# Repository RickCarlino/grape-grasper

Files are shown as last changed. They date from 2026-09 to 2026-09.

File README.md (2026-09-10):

# Precision Grasper

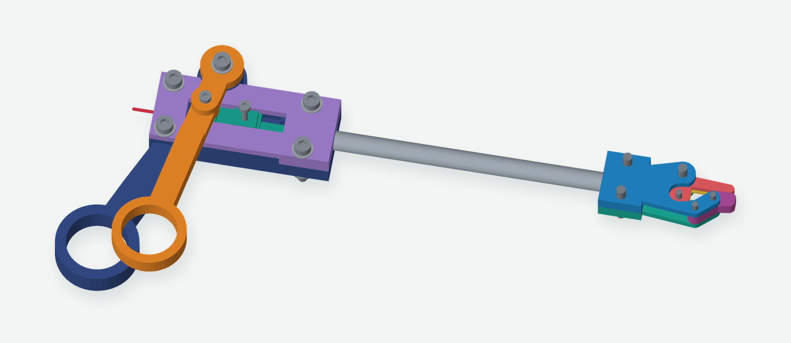
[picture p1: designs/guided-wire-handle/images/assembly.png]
Full assembly with the guided-wire lever handle and v2 printed head


A hand-operated precision grasper for dexterity practice and peeling grapes. Squeeze the lever to pull a wire through the metal tube and close the jaw; open it to push the wire back.

The newest handle provides **6 mm of wire travel** and **about 4.3:1 leverage**, matching the movement measured on the assembled v2 head. A sliding carriage guides the wire directly into the metal tube, and a through-hole lets excess wire exit the back. It reuses the v2 head, 116 mm tube, music wire, and the existing screw assortment.

**Status:** the v2 head is printed and assembled. Printing the 6 mm handle exposed a reversed cover: its print export was mirrored by mistake. **Corrected September 9:** print only the [replacement purple cover](designs/guided-wire-handle/bambu/guided-wire-cover-corrected-A1-PLA.3mf) if you already have the handle. The corrected part is digitally checked and sliced; its physical fit remains to be tested.

[Newest CAD](designs/guided-wire-handle/guided-wire-grasper.js) · [Guided-wire handle guide](designs/guided-wire-handle/README.md) · [Build log](#build-log)

## What to print

| Print | Files | Bambu A1 estimate |
| --- | --- | --- |
| Replacement purple cover — **September 9 correction** | [Cover-only 3MF](designs/guided-wire-handle/bambu/guided-wire-cover-corrected-A1-PLA.3mf) · [STL](designs/guided-wire-handle/stl/cover.stl) | **30 min / 4.83 g PLA** |
| Four guided-wire handle parts — **6 mm revision, corrected cover** | [3MF project](designs/guided-wire-handle/bambu/guided-wire-handle-A1-PLA.3mf) · [STL layout](designs/guided-wire-handle/stl/layout.stl) · [Assembly guide](designs/guided-wire-handle/README.md) | **2 hr 15 min / 28.55 g PLA** |
| Five head parts, only if you need a head | [3MF project](prints/fox-build-a1-head-v02/grape-grasper-head-v02-A1-PLA.3mf) · [Guide](docs/HEAD-V02.md) | **34 min / 4.49 g PLA** |

All projects use an A1 with a 0.4 mm nozzle, PLA, a textured PEI plate, 0.16 mm layers, and supports off. The handle uses five walls, 60% gyroid, and 2 mm brims. Confirm the installed nozzle and keep the supplied print orientations.

## The guided-wire handle

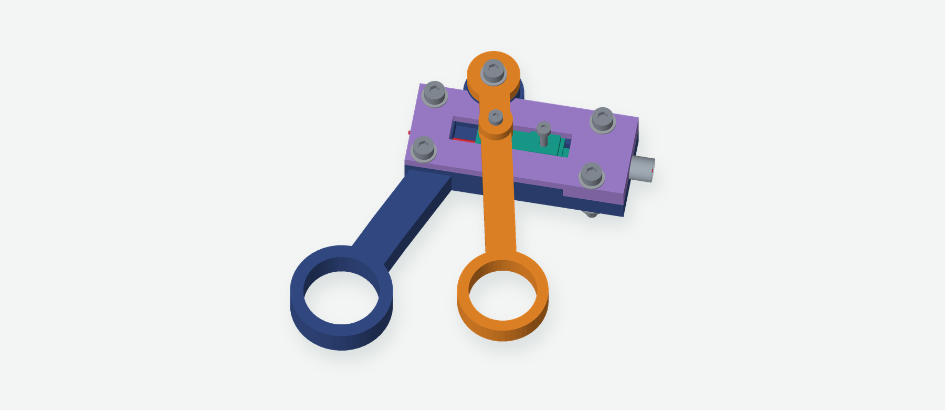
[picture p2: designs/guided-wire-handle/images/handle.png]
Guided-wire handle with its carriage cover fitted


The orange lever drives the green carriage through a metal screw engaging a transverse slot. A second screw clamps the wire directly inside the carriage. Its narrow guide telescopes into the tube, retaining at least 0.6 mm overlap during the working stroke. The wire runs beneath the drive screw and straight out of the rear frame hole, so its length is easy to adjust.

Working wire travel is **6.0 mm**, with 6.4 mm between the stops. The finger ring moves about 26 mm. The drive slot has 0.3 mm nominal reversal play. The stops limit travel, not gripping force. The full-assembly image is a closed reference; JSCAD's **Wire advance (mm)** slider demonstrates the new handle's complete stroke in the handle views. See the [guide](designs/guided-wire-handle/README.md) for adjustment and hardware placement.

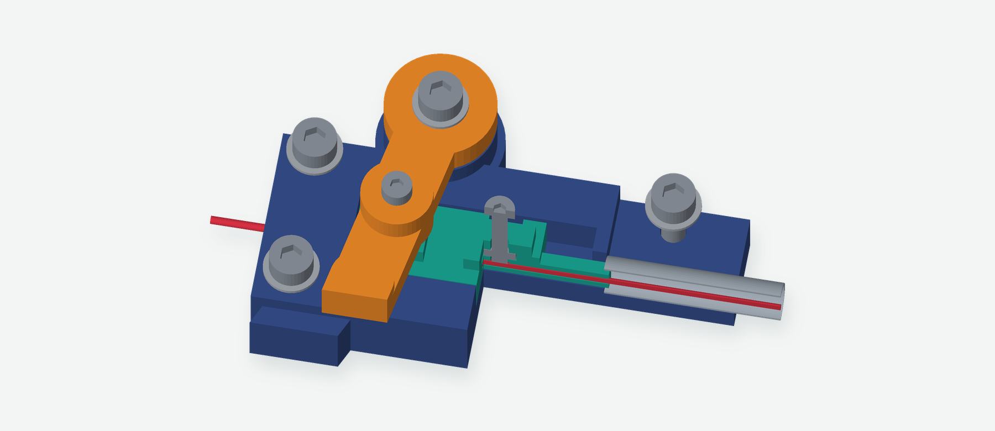
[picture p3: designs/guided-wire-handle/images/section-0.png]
Section through the carriage clamp and short wire guide


The earlier [three-part direct-clamp lever](docs/LEVER-HANDLE.md) remains as a reference. Its long exposed wire span is why the guided version was developed. The root-level handle STLs and `precision-grasper.js` belong to that earlier design; use the new files linked above for this prototype.

## The printed head

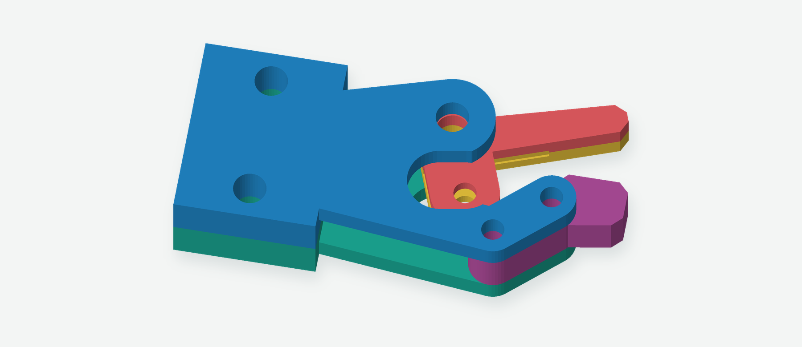
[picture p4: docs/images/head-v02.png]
The assembled design retains the v2 printed gripper head


The v2 head has two cheeks, two moving-jaw halves, and a fixed tip insert. Its closed printed envelope is **43 × 18.34 × 9.4 mm**, excluding fasteners. It printed and assembled successfully, although it still feels bulky for small openings.

The [compact metal-head plans](concepts/metal-head-v03/README.md) and [clip research](docs/CLIP-OPTION.md) are saved for later.

## Build log

### First PLA print — September 5, 2026

The handle printed well. The first head was bulky, and its raised features failed to print cleanly. That led to a smaller head made from flat-printing parts.

| On the printer | Head close-up |
| --- | --- |
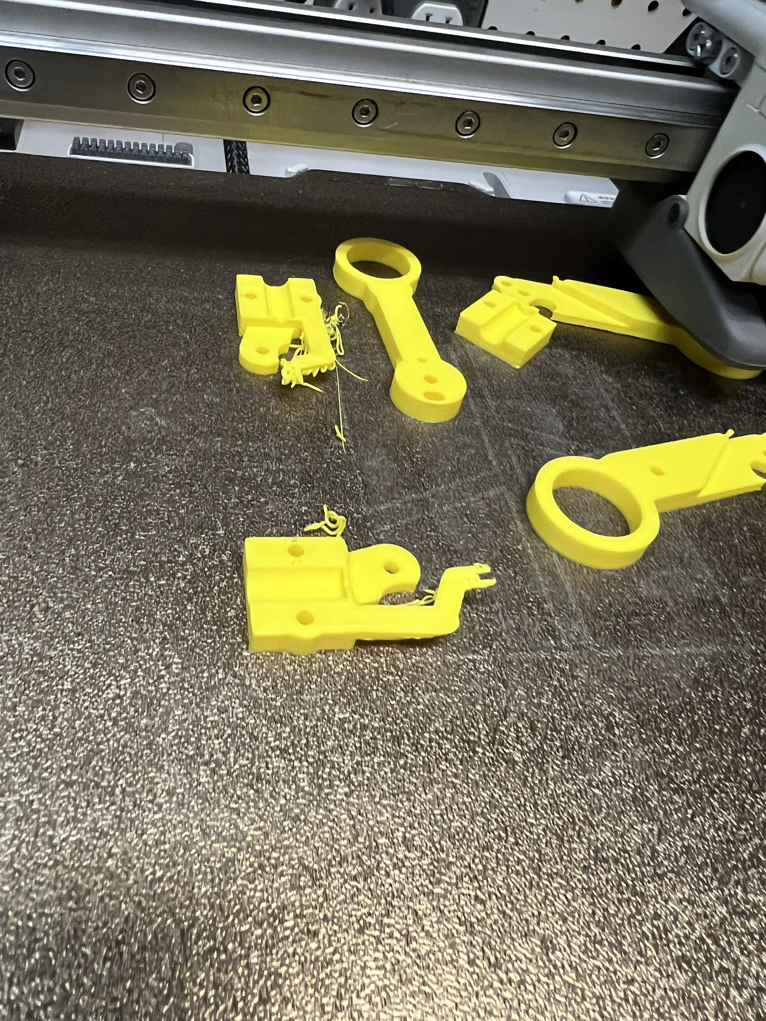
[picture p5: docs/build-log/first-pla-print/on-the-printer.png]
First PLA print on the bed
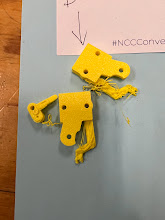
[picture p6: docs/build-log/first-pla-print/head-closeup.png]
Failed features on the first head
|  |  |

### v2 assembled — September 6, 2026

The revised head printed and was assembled on the metal tube. Moving the handle mechanism moved the jaw, but attaching the wire at the trigger remained awkward. A slimmer metal head was explored and saved for later.

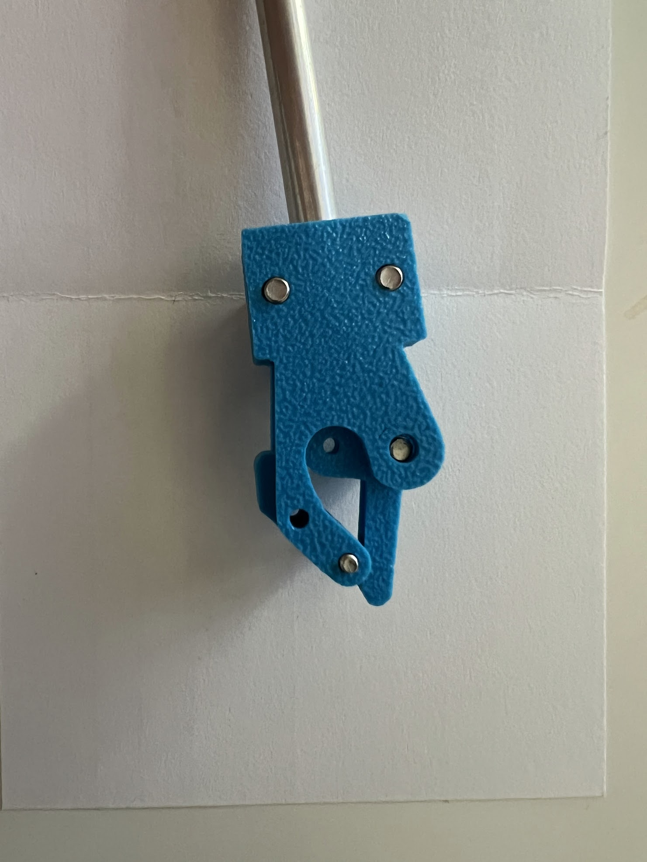
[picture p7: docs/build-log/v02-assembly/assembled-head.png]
Blue printed v2 head assembled on its metal tube
[](docs/build-log/v02-assembly/assembled-head.png)

### A simpler lever handle — September 6, 2026

The replacement handle starts fresh with a fixed grip, a squeeze lever, and a tube cap. One M2 screw clamps the straight wire directly in the lever, making its length easy to adjust. The long finger arm keeps the leverage.

The nut loads from the side, and a thin washer supports the lever pivot. This version was modeled and sliced. Its long exposed wire span raised a concern about bowing when pushed.

### Keeping the wire supported — September 6, 2026

A sliding screw clamp and fixed guide reduced the unsupported wire span at the handle. The first version had too little travel for the assembled head.

### Six millimetres and a rear wire exit — September 6, 2026

Measuring the assembled v2 head established a 6 mm wire stroke. The handle now provides that travel while retaining leverage. Its guide slides inside the tube, and excess wire passes beneath the drive screw and out the back. The four matching parts have been checked and freshly sliced for the A1: **2 hr 15 min, 28.55 g PLA**. That print exposed the cover orientation error described below.

### Cover orientation corrected — September 9, 2026

The 6 mm handle was printed, but the purple cover’s circular relief was on the wrong side. A wing had to be cut away to fit it. The print export had reflected the part instead of rotating it onto the bed; the assembly preview therefore looked right while the printed part was reversed.

The cover export and Bambu projects are corrected. Only the cover needs reprinting: **30 min, 4.83 g PLA**. The frame, lever, and carriage are unchanged. Checks now turn the exported cover over as a real part would be fitted and confirm that it clears the frame. An orientation audit found no other reversed parts in the current nine-part build. The replacement still needs a physical fit test.

## Parts to buy or find

The build uses **one of each of the three products below**. These are the recorded September 5 offers, not a new price or delivery check. Their full-pack subtotal was **$20.67** on Amazon on September 5, 2026, excluding tax, any shipping charges, tools, filament, and socket shims. Prices and availability can change; check the selected offer on Amazon before ordering.

Amazon links below are affiliate links. As an Amazon Associate I earn from qualifying purchases.

| Product to buy | Specification and use | Pack price |
| --- | --- | ---: |
| [K&S 8106 round aluminum tube — 1 tube](https://www.amazon.com/dp/B00FZS20P0?tag=rickcarlino-20) | **1/4 inch (6.35 mm) OD × 0.014 inch wall × 12 inches long**. Calculated nominal ID is **5.64 mm**. Cut one **116 mm** piece and deburr it. This is the lower-cost aluminum option for the metal shaft. | **$6.19** |
| [K&S 5497 music wire — 4 lengths](https://www.amazon.com/dp/B002WXPNA0?smid=A2E137HZ093DQ5&psc=1&tag=rickcarlino-20) | Select **0.039 inch OD × 12 inches long**, approximately **0.99 mm diameter**. Start with about **170 mm** before forming the head-end eye and trimming the straight handle end. This is carbon spring steel for the dry internal linkage, not the contact tips. The quoted offer is from **Hobbylinc**. | **$6.29** |
| [HanTof 900-piece hex socket head cap screw, nut, and washer assortment](https://www.amazon.com/dp/B0FF4RH81S?tag=rickcarlino-20) | Select **900-Pieces Set**, with M2, M2.5, and M3 hardware and black Grade 12.9 alloy-steel cap screws. The listed contents include **25 × M3 × 20 mm**, **25 × M2 × 12 mm**, **100 nuts and 100 flat washers of each size**, plus hex keys. One kit covers all the fasteners below. | **$8.19** |
| **Total: one tube pack + one wire pack + one hardware kit** | Extra wire and fasteners remain for spares and later builds. | **$20.67** |

Shipping is not included in the recorded subtotal. Confirm the current offer and delivery date at checkout.

### Hardware for the complete grasper

| Hardware | Quantity | Use |
| --- | ---: | --- |
| M3 × 20 mm screws and M3 nuts | 8 each | Handle pivot, four guide-cover screws, head pivot, and two head tube-clamp screws |
| M3 flat washers | 16 | Ten at the handle and six at the head; the washer below the lever is 0.5 mm thick |
| M2 × 12 mm screws and M2 nuts | 5 each | Head linkage, two fixed-tip screws, handle wire clamp, and lever drive pin |
| M2 flat washers | 6 | Head joints |

The guided handle uses five M3 screw/nut sets, ten M3 washers, and two M2 screw/nut sets. Its M2 nuts are nominally 4 mm across flats × 1.6 mm thick. The pivot M3 nut loads into the frame from below; there is no bottom washer at that joint.

Also needed: PLA, approximately 1 mm music wire, the 6.35 mm OD tube cut to 116 mm, and ordinary cutting, filing, measuring, and assembly tools. Both complete print plates use about **33.04 g of PLA** including brims.

## Files and checks

- [Newest design and assembly instructions](designs/guided-wire-handle/README.md): self-contained JSCAD, four STLs, images, and the new A1 project.
- [Motion checks](designs/guided-wire-handle/checks.json): 122 push/pull positions, nut and screw insertion, hardware clearances, and stop contact.
- [Mesh/layer checks](designs/guided-wire-handle/mesh-checks.json) and [slice checks](designs/guided-wire-handle/bambu/slice-checks.json): four closed meshes, no floating islands, matching embedded project meshes, first-layer paths, and G-code checksum.
- [Orientation audit](orientation-checks.json): all nine current parts match the intended assembly after physical rotations; the saved Bambu models match their STLs. The report also covers earlier parts and records its limits.
- [Head guide](docs/HEAD-V02.md): the existing v2 head is unchanged.

These are digital checks. Fit, grip, drive-slot wear, and PLA relaxation still need physical testing. The tube bore is much larger than the wire, so supporting the handle end does not rule out bowing inside the tube. Adjust the pivot screw for free rotation; fully tightening it can bind the lever. The old head CAD does not establish its as-built full-stroke clearances; use the actual assembled head when setting the wire length.

<details>
<summary>Earlier direct-clamp handle and unchanged head — reference STL previews</summary>

<!-- STL-GALLERY:START -->
<!-- Generated by scripts/render_stls.py; do not edit this section. -->
### Printable parts

Print one of each of the three handle parts and five head parts, or their two separate layouts. Keep an already assembled head. Dimensions shown are STL bounds; previews are individually scaled.

| Part | STL preview |
| --- | --- |
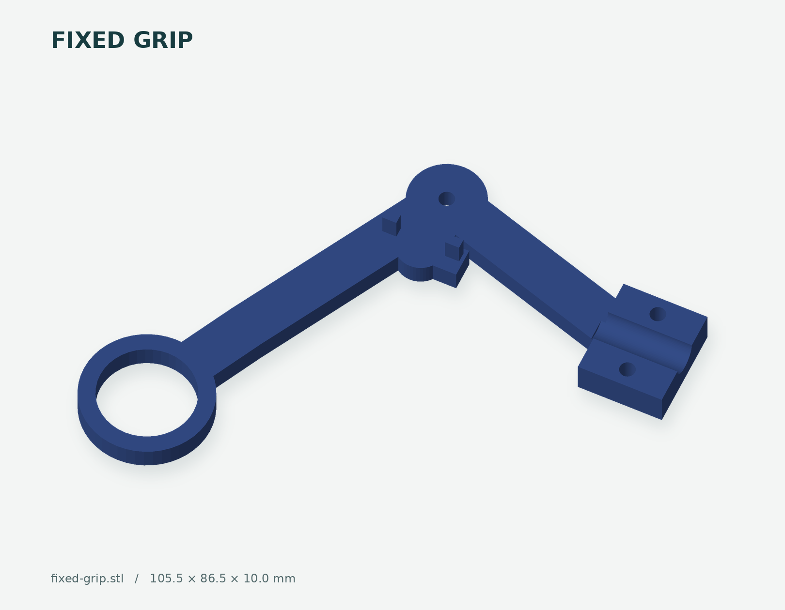
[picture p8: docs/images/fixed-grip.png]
Fixed grip STL preview
| [Fixed grip](fixed-grip.stl) | [](fixed-grip.stl) |
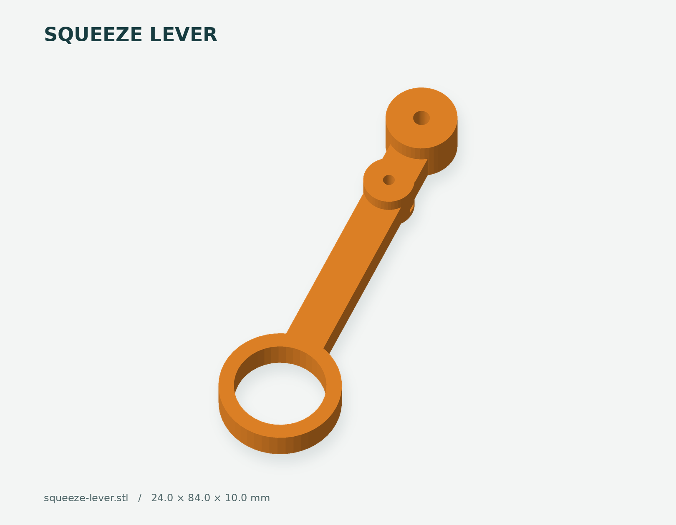
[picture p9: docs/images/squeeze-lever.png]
Squeeze lever STL preview
| [Squeeze lever](squeeze-lever.stl) | [](squeeze-lever.stl) |
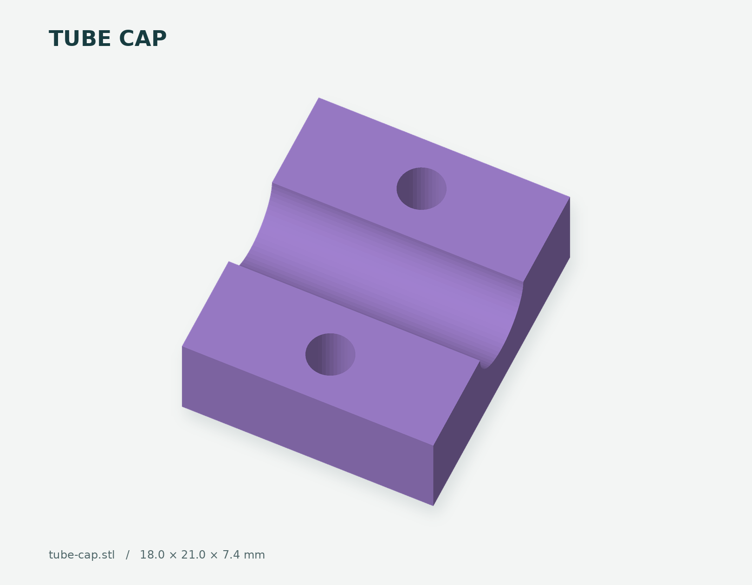
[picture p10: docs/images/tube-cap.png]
Tube cap STL preview
| [Tube cap](tube-cap.stl) | [](tube-cap.stl) |
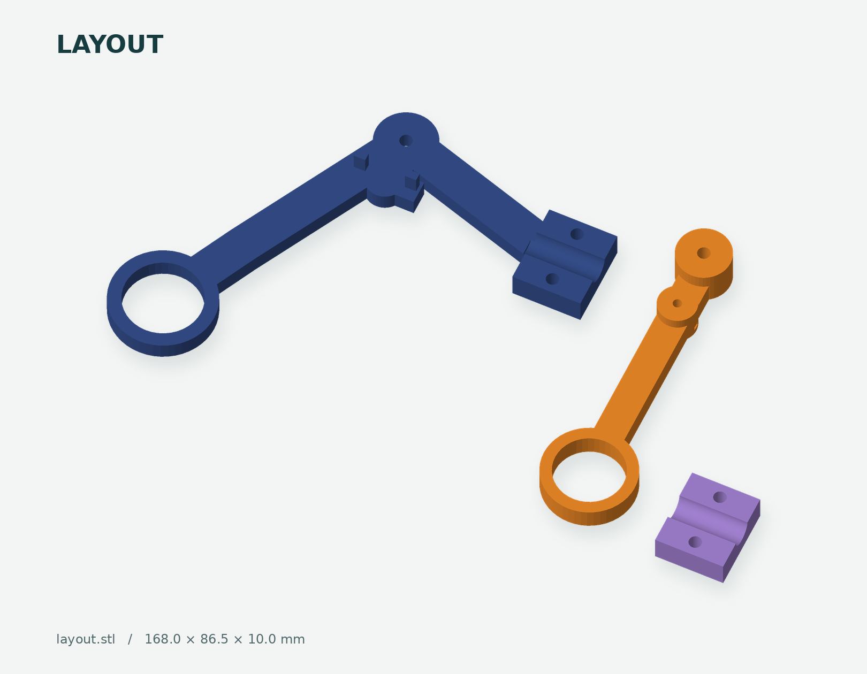
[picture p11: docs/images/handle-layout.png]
Handle print layout STL preview
| [Handle print layout](layout.stl) | [](layout.stl) |
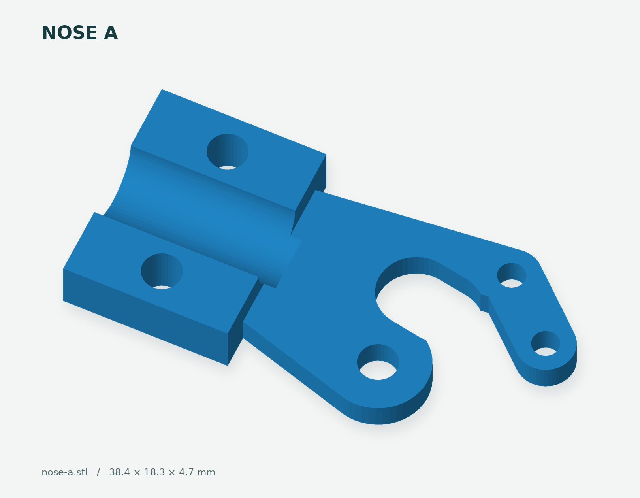
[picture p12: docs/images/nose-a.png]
Nose A STL preview
| [Nose A](nose-a.stl) | [](nose-a.stl) |
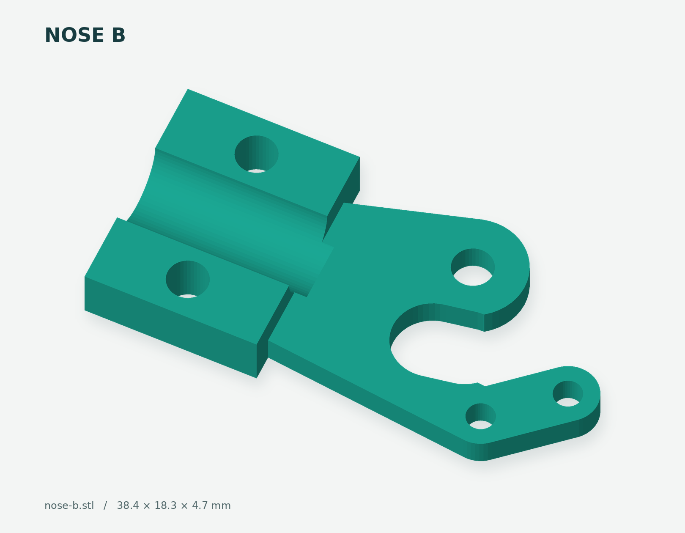
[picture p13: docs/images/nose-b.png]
Nose B STL preview
| [Nose B](nose-b.stl) | [](nose-b.stl) |
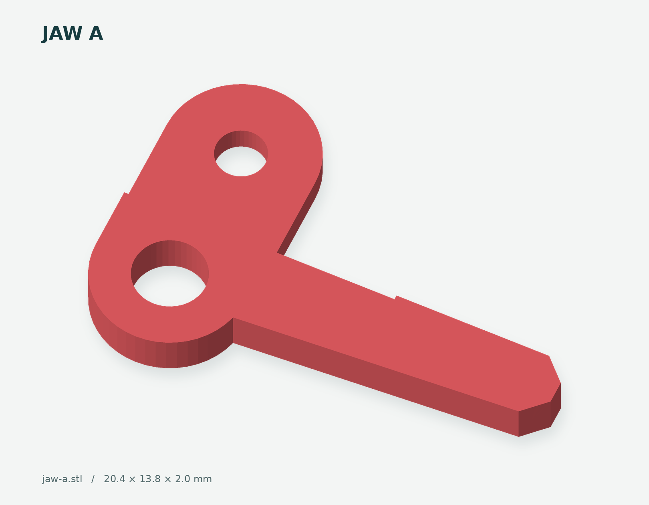
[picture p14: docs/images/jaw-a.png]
Jaw A STL preview
| [Jaw A](jaw-a.stl) | [](jaw-a.stl) |
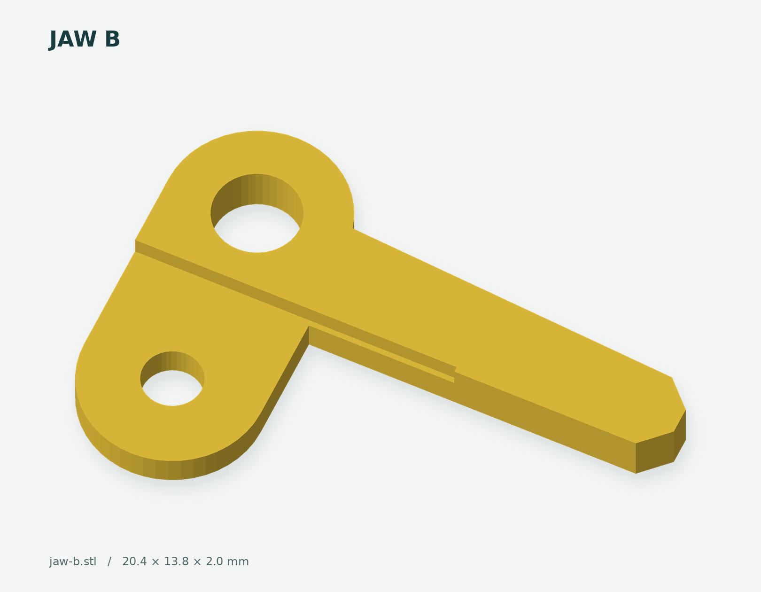
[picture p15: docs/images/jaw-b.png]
Jaw B STL preview
| [Jaw B](jaw-b.stl) | [](jaw-b.stl) |
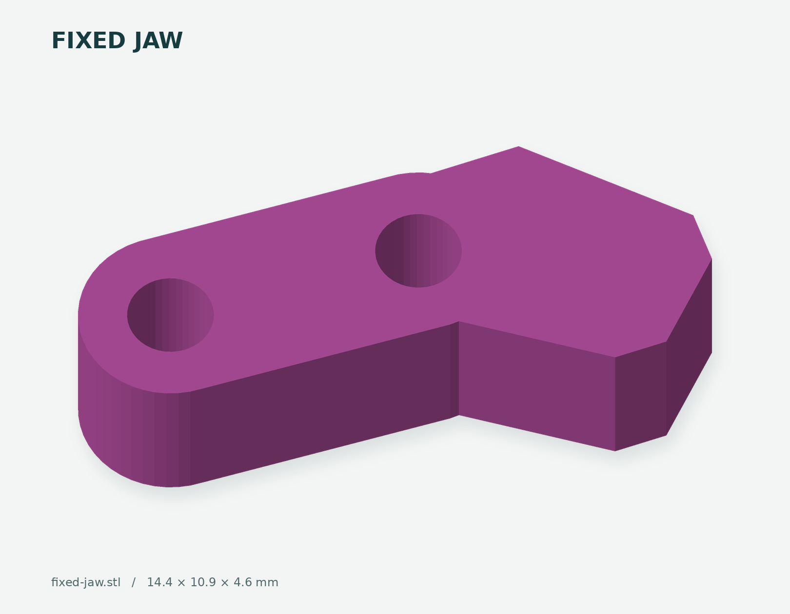
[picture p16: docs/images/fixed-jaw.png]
Fixed tip insert STL preview
| [Fixed tip insert](fixed-jaw.stl) | [](fixed-jaw.stl) |
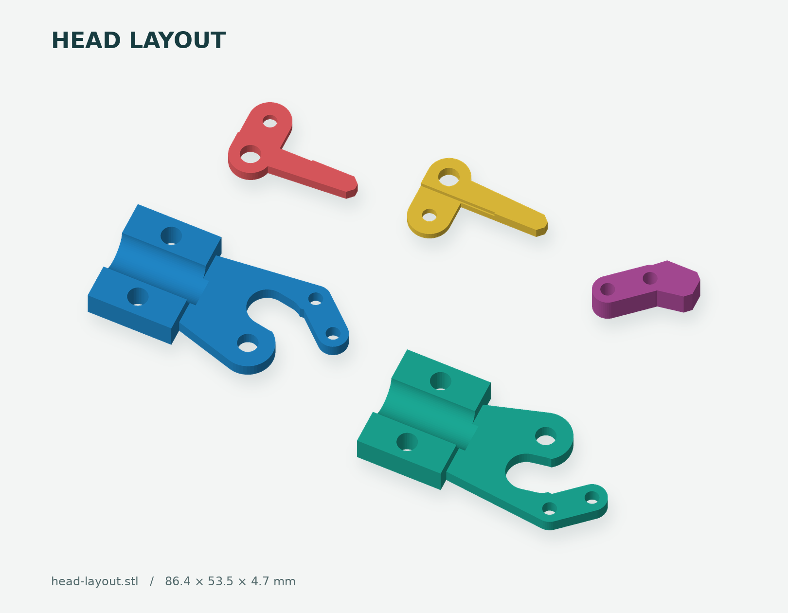
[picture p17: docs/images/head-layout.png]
Head print layout STL preview
| [Head print layout](head-layout.stl) | [](head-layout.stl) |
<!-- STL-GALLERY:END -->

</details>

## Rebuild and check

Use the [guided-wire build commands](designs/guided-wire-handle/README.md#checks-and-limitations) for the new model. They regenerate its source-derived STLs, images, and checks. The saved Bambu project must be resliced separately after geometry changes.

`make screenshots` and `node scripts/check_motion.cjs` still rebuild/check the earlier direct-clamp model retained at the repository root. Its images and STLs are reference files, not the new guided-wire handle.

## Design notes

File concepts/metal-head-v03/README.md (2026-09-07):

# Compact metal gripper head — v0.3 concept

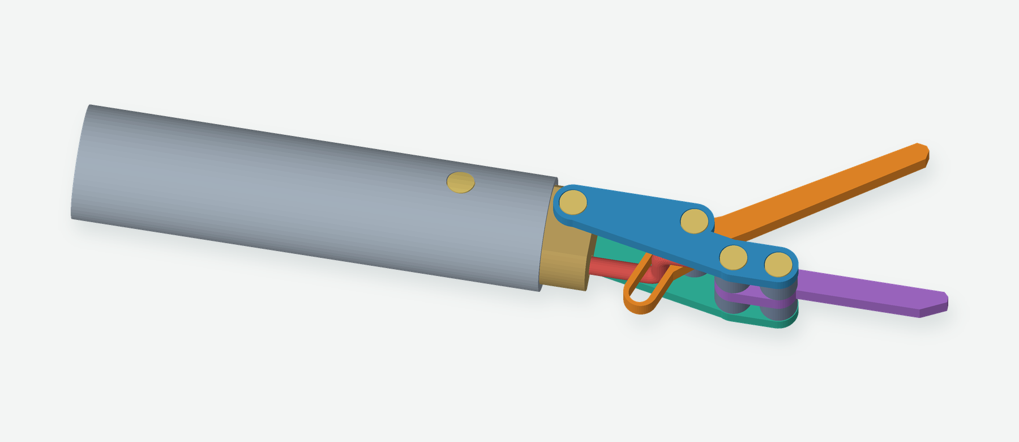
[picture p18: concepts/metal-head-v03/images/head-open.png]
Metal head with separate colored parts


A metal replacement for the printed nose. Two 0.8 mm side plates support a 1 mm moving jaw and a 1 mm fixed jaw. A small metal insert transfers the load into the existing tube. The colors identify parts; all head structure shown here is metal.

**Status: parked for later.** Work is continuing with the assembled v0.2 printed gripper. These metal-head plans are preserved as a dimensional motion model, not a proven build. The closed geometry occupies a 6.90 mm circular envelope around the shaft axis. An 8 mm hole is the proposed first fit check. The wire bend and flush pin retention still need bench trials before this becomes a fabrication release.

## Inspect it in JSCAD

Open [JSCAD](https://jscad.app/) and paste or load `metal-head.js`. The view selector provides the assembled head, an exposed mechanism, an exploded view, a closed head beside an 8 mm hole gauge, flat sheet parts, individual parts, and a full 116 mm shaft.

Move **Jaw opening** from 0 to 35 degrees. The jaw and wire follow the same geometric constraint in every view. The mechanism view hides the front side plate, its pins and the spacers so the drive slot is visible.

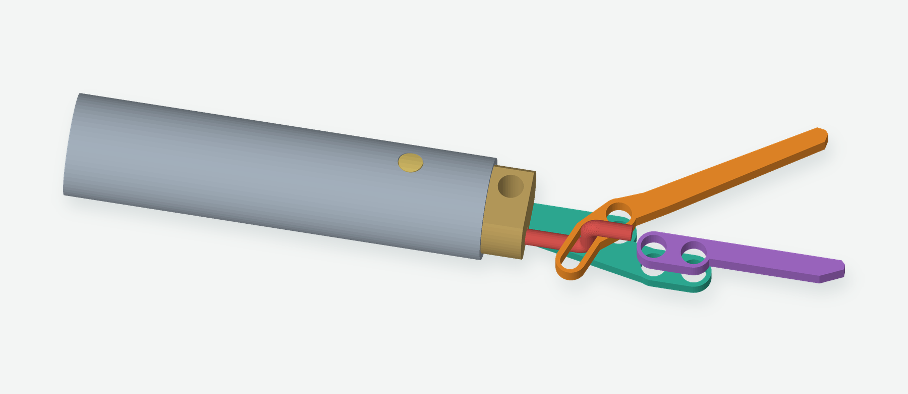
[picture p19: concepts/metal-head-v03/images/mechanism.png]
Pushrod driving the slot in the moving jaw


## How it works

The front end of the 1 mm pushrod has a Z bend. Its straight transverse section passes through a 1.2 mm wide slot in the moving jaw. Pulling the rod rotates the jaw closed; pushing it opens the jaw. The return bend captures the jaw between the two parallel portions of the wire.

The slot is straight and can be drilled at its ends and carefully filed between them. It is angled to turn the existing handle's nominal **2.394 mm rod travel into 35 degrees of jaw rotation**. The resulting opening at the working end is about 7.6 mm. The model retains direct push/pull control; it does not use an alligator clip's spring.

The required wire stroke matches the current handle, but the wire's end shape, offset and finished length change. This model checks the head and its required travel. It does not model or certify the revised connection through the complete handle assembly.

## Nominal dimensions and stock

| Item | Modeled size | Quantity |
| --- | --- | --- |
| Existing shaft | 6.35 mm OD, assumed 5.64 mm ID; 116 mm long | 1 |
| Side plates | 0.80 mm sheet; each about 13.95 × 4.05 mm | 2 |
| Moving jaw | 1.00 mm sheet; about 18.95 × 3.65 mm | 1 |
| Fixed jaw | 1.00 mm sheet; about 12.85 × 2.10 mm | 1 |
| Tube insert | 5.50 mm OD × 11.50 mm long; 9 mm enters tube | 1 |
| Insert flats | 3.80 mm across the two faces on the nose | 2 faces |
| Pin holes / pins | 1.60 mm holes / 1.50 mm pins | 5 pins |
| Fixed-jaw spacers | 2.10 mm OD, 1.60 mm bore, 1.40 mm long | 4 |
| Pivot spacers | 2.10 mm OD, 1.60 mm bore, 1.30 mm long | 2 |
| Wire passage in insert | 1.20 mm diameter; offset Y −0.80, Z −1.30 mm | 1 |
| Drive slot | 1.20 mm wide; see template for angle and endpoints | 1 |

The exposed nose extends approximately **22.3 mm beyond the tube end**. The insert is partly inside the tube. Both gripping faces are 1 mm wide and nominally meet when closed.

Brass sheet is a reasonable material for a first mechanism trial; use stainless for the finished contact jaws if the geometry works. Spacer dimensions are fit envelopes, not verified catalog part numbers. Thin tubing may be usable after checking its actual bore and outside diameter. Measure the real tube and sheet before adapting the source parameters.

## Making a trial

Use `sheet-templates.svg` for the four flat profiles. It is a 1:1 drawing with a 20 mm calibration line; print at 100% and measure that line. The profiles are projected from the actual CAD solids, including their holes and slot. Allow for tool kerf and file to size.

The insert can be drilled from round stock and its two nose flats filed. Its tube-retaining cross-pin sits 5 mm behind the tube end. The other cross-pin holds the two side plates to the exposed insert. The fixed jaw is secured between the plates with two pins and four spacers. The moving jaw has one pivot with 0.10 mm axial clearance to each spacer.

The **tight Z bend is the main fabrication uncertainty**: its modeled centerline bend radius is 0.70 mm in 1 mm wire. Trial-bend the actual supplied wire and check for cracking and springback. The captured bend may need to be formed with the jaw on the wire, before installing the side plates. A larger bend will require more clearance and a revised model.

The displayed pins have flush finished ends to show the intended clearance envelope. They still need a retention method. Soft brass pins could be riveted for the prototype, with the end shape and riveting allowance worked out on a sample. Do not assume a cut steel dowel will stay in place, or clamp the moving jaw tightly while riveting. Actual retained fasteners must be included in the hole-fit trial.

## Files and checks

- `metal-head.js`: self-contained JSCAD source; dimensions are in `M` near the top.
- `sheet-templates.svg`: 1:1 profiles for the four sheet parts.
- `stl/`: five solid inspection models, including the insert. These are metal-part references, not a sliced PLA print package.
- `checks.json`: no modeled collisions at 36 samples from 0 to 35 degrees; slot constraint and stroke checked against the handle's nominal travel.
- `stl/mesh-checks.json`: all five exported meshes have one body, consistent winding and closed surfaces.
- `template-checks.json`: projected profile area × thickness agrees with each solid's volume to within 0.001 mm³.

The checks cover nominal geometry. They do not establish grip force, friction, wear, wire fatigue, manufacturing tolerance or assembled pin retention. The current printed v2 head and its print files remain in the repository.

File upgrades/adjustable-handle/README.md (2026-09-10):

# Superseded handle print record

The old handle source and part STLs have been removed. Use the [current 6 mm guided-wire handle](../../designs/guided-wire-handle/README.md) and its corrected Bambu A1 project. The projects in this folder are historical print records.

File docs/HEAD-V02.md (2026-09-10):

# v0.2 replacement head — print and assembly

Revised head

This is the v2 head used with the current guided-wire lever handle. If it is already assembled, keep it. Otherwise, print one each of `nose-a.stl`, `nose-b.stl`, `jaw-a.stl`, `jaw-b.stl`, and `fixed-jaw.stl`, or print the combined `head-layout.stl`. These five parts replace the original two nose halves and one-piece jaw.

The new head is **43 × 18.34 × 9.4 mm** closed, excluding hardware protrusions. Its printed material volume is about **39.5% lower** than v0.1. The front cheek plates stop behind the gripping face. The 4 mm moving and 4.6 mm fixed contact tips trade a little contact width for more robust filament printing.

The two cheeks now include **2.4 mm reinforcing webs** filling the rear triangular windows. The rod passage and rounded linkage access remain open. Blue and teal identify the cheeks, coral and yellow the moving jaw halves, and magenta the fixed insert. Preview colors are for identification; use a single PLA filament for the supplied slice.

## Print

The supplied [A1 print package](../prints/fox-build-a1-head-v02/PRINT-GUIDE.md) estimates **33 minutes 33 seconds and 4.49 g of PLA**, including brims. It uses a 0.4 mm nozzle, textured PEI plate, 0.16 mm layers, 4 walls, 50% gyroid, and 2 mm outside brims. **Supports are off.** Each part's continuous broad face starts on the bed. Keep the supplied orientations: grooves and shallow pockets face upward.

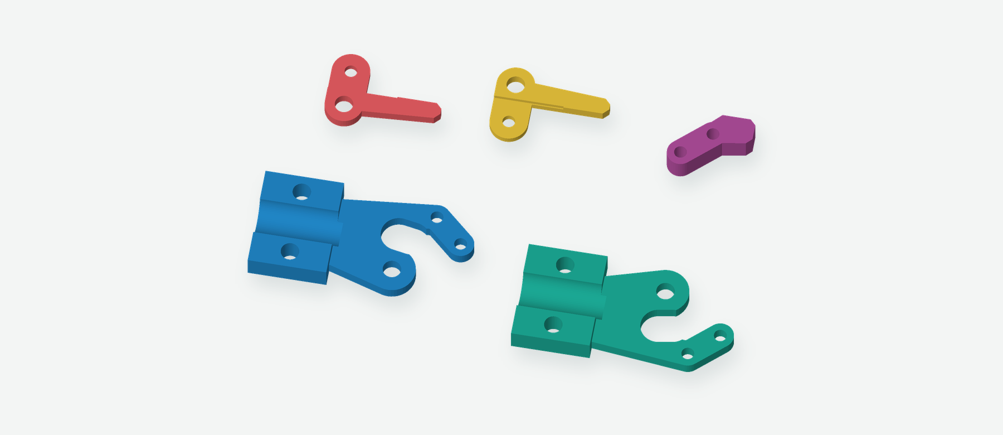
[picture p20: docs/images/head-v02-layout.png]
Five pieces laid flat


After printing, remove brims and clean mating edges. The 4.0 mm moving jaw fits a 4.6 mm fork, leaving 0.3 mm clearance per side. Clean the 3.25 mm pivot and 2.25 mm link/mounting holes gently until fasteners slide through. Remove any stringing from the 1.5 mm central rod slot.

## Handle connection

The current [guided-wire handle](../designs/guided-wire-handle/README.md) clamps the straight wire in its sliding carriage. Keep one formed eye at the jaw. Fit the wire after seating both ends of the tube, then trim the straight tail according to the handle guide.

## Hardware and assembly

Use the 116 mm tube, approximately 1 mm pushrod with its head-end eye, three M3 × 20 mm head fasteners (one pivot and two tube-clamp screws), and one M2 linkage screw. Add **two M2 × 12 mm screws, two M2 nuts, and four thin M2 washers** for the fixed-tip insert. These are additional pieces of the same sizes in the existing assortment. Use washers no more than 5 mm OD on the insert. The 9.4 mm stack plus thin washers and nut fits a 12 mm screw nominally; verify full nut engagement, or use longer M2 screws if needed.

1. Face the shallow pockets of Jaw A and Jaw B inward and put the rod eye into their combined slot. Install the M2 linkage screw through the two halves and the eye, leaving the eye free to turn.
2. Put the fixed insert between Nose A and Nose B, with its flat contact face toward the moving jaw. Its two staggered holes match the small holes along the cheeks' lower arms. Secure those two M2 mounting screws.
3. Place the split moving jaw between the cheeks and pass the M3 pivot through both cheeks and both jaw halves. Tighten only enough to retain it while allowing free rotation.
4. Fit the 116 mm tube into the head's two half-round seats and install the two M3 clamp screws loosely. The head pivot lies 12 mm beyond the tube end. Seat the other end 18 mm into the current handle socket and align the jaw's opening plane with the lever's motion. The new handle geometry sets the spacing; the earlier pivot-to-pivot measurement no longer applies.
5. Shim the tube sockets as necessary, secure gently, and check closed-tip contact. Cycle at least 20 times before gripping a paper strip. Watch for binding, flexing of the split jaw, and lateral tip mismatch.

The head-end motion and wire eye are unchanged. This head has been printed and assembled. The guided-wire handle has also been printed; its corrected cover still needs a fit test. See the [current build status](../README.md) for the latest print files. Its 1.25 mm thick crank cheeks beside the central wire slot deserve particular inspection during the first gentle fit test.

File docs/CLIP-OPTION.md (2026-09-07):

# Off-the-shelf clip option — parked research

These are saved candidate notes and historical prices from September 5, 2026. The current prototype uses the printed v0.2 head. No clip adapter has been built or validated.

**Yes, with an adapter.** A useful candidate is the **Mueller BU-34 smooth-jaw micro clip**, or **BU-34X** in stainless steel. The manufacturer's [BU-34 series datasheet](https://www.muellerelectric.com/product_files/229/DS-BU-34.pdf) specifies approximately **27.8 × 5.1 × 7.9 mm**, with up to **5.6 mm jaw spread**. Smooth jaws make this a more relevant starting point than a coarse-toothed electrical clip, though grip on grape skin still needs testing.

| Candidate | Material | Listed single-piece price, checked September 5, 2026 |
| --- | --- | --- |
| [Mueller BU-34 at DigiKey](https://www.digikey.com/en/products/detail/mueller-electric-co/BU-34/304581) | Nickel-plated steel | **$0.66**, before tax/shipping |
| [Mueller BU-34X at DigiKey](https://www.digikey.com/en/products/detail/mueller-electric-co/BU-34X/4766487) | Stainless steel | **$1.17**, before tax/shipping |

A proposed conversion would hold the clip's fixed shank in a printed cradle and put a sliding cam on the pushrod. Advancing the rod would press the clip's rear lever to open it; retracting the rod would release the lever and let the clip spring close. That preserves the current squeeze-to-close direction, but **grip force would come from the clip spring**, rather than direct control through our jaw linkage.

This is an engineering concept, not a validated drop-in adapter. The catalog gives overall dimensions, not the tail/pivot geometry or spring force needed to finish a reliable mount and cam. Measure one sample's mounting shape, lever travel, and opening force, and verify that our **2.39 mm rod stroke** gives sufficient travel. Simply attaching the rod to the solder/crimp tail will not actuate the jaw. A rigid push/pull conversion with controllable closing force would need a separate crank and likely clip modification. The supplied v0.2 files implement the printed head; they do not claim compatibility with an unmeasured clip.

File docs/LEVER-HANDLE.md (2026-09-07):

# Direct-clamp lever handle

**Previous design:** the [guided-wire handle](../designs/guided-wire-handle/README.md) replaces the long exposed wire span with a lever-driven carriage and fixed guide. These files remain as a reference.

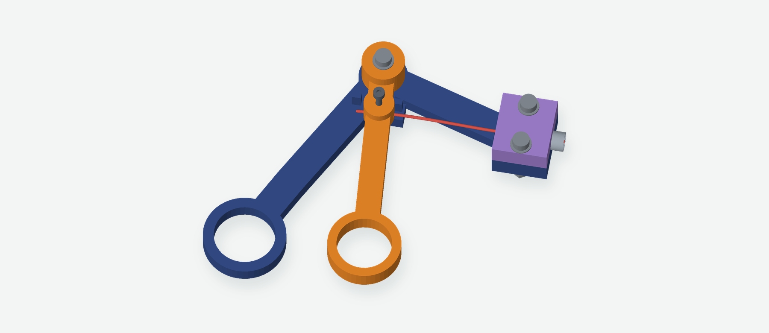
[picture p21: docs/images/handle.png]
Three-piece lever handle


The handle has three printed parts: a fixed grip, a squeeze lever, and a tube cap. An M2 screw presses directly onto the straight wire inside the lever. A captive metal nut supplies the threads. The lever pulls the wire when squeezed and pushes it when opened.

The finger ring is 65 mm from the pivot and the wire is 15 mm from it: **about 4.3:1 nominal leverage**. Roughly 10.4 mm of finger travel produces 2.39 mm of rod travel. The lever rotates only 9.15° while the existing v2 jaw rotates 20°.

## Print and hardware

Print [the three-part A1 project](../prints/fox-build-a1-lever/grape-grasper-lever-A1-PLA.3mf), or one each of [fixed-grip.stl](../fixed-grip.stl), [squeeze-lever.stl](../squeeze-lever.stl), and [tube-cap.stl](../tube-cap.stl). The supplied STLs have their broad faces on the bed. The cap's tube groove faces up in the print and down in the assembly.

| Hardware for this handle | Quantity | Location |
| --- | ---: | --- |
| M3 × 20 mm screw, nut, and two thin washers | 3 sets | Lever pivot and two tube-cap holes |
| M3 washer, 7 mm OD × 3.2 mm ID × 0.5 mm thick | 1 | Between the fixed grip and lever at the pivot |
| M2 × 12 mm screw and M2 nut | 1 set | Wire clamp |

The clamp nut is modeled as **4 mm across flats × 1.6 mm thick**. Its side-loading pocket is 4.2 mm across flats × 1.8 mm high. The M2 × 12 screw in the existing kit works, but its head stands above the lever. An M2 × 8 screw also works. M2 × 6 is too short: its head reaches the housing before its tip reaches the wire. No separate clamp carrier or clamp washer is required.

## Assemble and adjust

1. Remove the brims and clean the wire passage and nut pocket. Slide the M2 nut into the open side slot from the wire-tail side (opposite the tube). Start the M2 clamping screw from above, leaving its tip clear of the wire passage.
2. Put the additional 0.5 mm M3 washer on the fixed grip’s pivot, then place the lever over it. Install the M3 pivot with one more washer at each outside face: three washers at this joint altogether. Leave the lever free to rotate; snug the nut only enough to remove excess play. The middle washer supports the lever 0.5 mm above the fixed frame. Check the actual washer thickness and confirm the lever turns freely before attaching the wire.
3. Seat the 116 mm tube in the fixed grip, flush with the socket's rear edge, then fit the cap and its two M3 screws. The tube enters this socket by 18 mm and the existing head socket by about 13 mm. Align the jaw's opening plane with the lever's motion and tighten the tube clamps gently. The sockets are 6.65 mm in diameter for a 6.35 mm tube. If the mating faces meet while the tube still slips, use a thin tape or paper wrap in the socket; extra screw torque will not remove that clearance.
4. Keep the single formed eye at the existing head. Feed the straight handle end through the tube and then through the lever's flared passage. The passage is open at both ends; no handle-end eye needs to be threaded or formed.
5. Bring the jaws just closed with the lever slightly short of its closing stop. Slide the wire to length, leaving a 5–8 mm straight tail behind the clamp, and gently tighten the M2 screw onto it. The screw tip presses the wire into the printed floor. Make a witness mark beside the clamp so slipping is easy to see.
6. Cycle gently and adjust as needed. Confirm full opening, free return, no wire slip, and no permanent kink in the exposed wire. Try holding a paper strip before peeling a grape. Recheck the clamp after several cycles.

**Wire length changes:** the new clamp is about 169 mm from the head's eye center when closed. An old wire cut for the original handle may be too short. Start with roughly 195–200 mm of stock, allow for the head eye, then trim the straight tail after fitting. The existing tube and head can be reused.

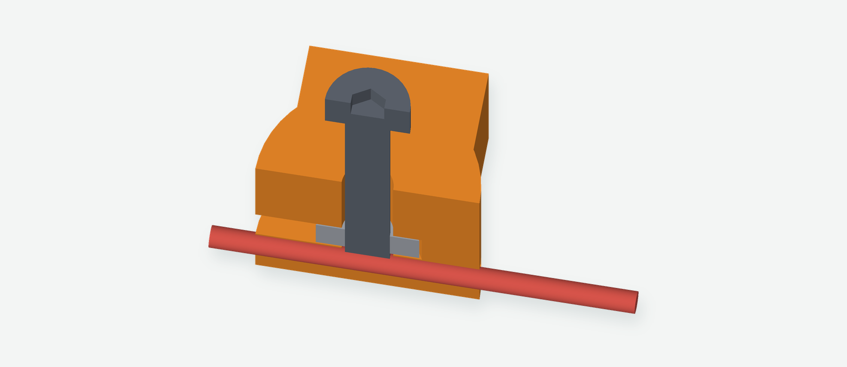
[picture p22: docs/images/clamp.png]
Section through the integral clamp: screw, captive nut, red wire and printed floor


## Why leave some wire exposed?

The clamp moves through a small arc while the tube stays fixed. About 40 mm of exposed wire between them accommodates that rotation. The passage flares at its ends to allow angular relief. The red curved wire in CAD illustrates this flex; its shape is not a structural simulation. Actual springback, grip, and fatigue still need a bench test.

## What the endstops do

The two small lugs are printed into the fixed grip. The lever's round clamp boss contacts them just beyond each end of the working stroke. They limit excessive opening and pulling after the wire length is adjusted.

They do **not** add leverage or limit gripping force. If the wire is set too long, the closing stop could prevent the jaws from closing; if set too short, the rod could be over-pulled before reaching the stop. Adjust at the jaws, then confirm both ends of travel. Their strength has not been tested in a print.

## Checks and current status

The [motion checks](../motion-checks.json) test 81 positions at 0.25° intervals from 0 to 20° of jaw opening. They check the lever, frame, pivot hardware, screws, wire, tube, and moving head for intersections. The nut is also tested at 41 positions while sliding into its side port, and both M2 × 8 and M2 × 12 screws are checked during insertion. Additional checks just beyond the stroke confirm stop contact. The head matches the retained v2 geometry.

The [STL checks](../mesh-checks.json) verify all eight separate watertight parts and the three-body handle layout. The [slice checks](../prints/fox-build-a1-lever/slice-checks.json) compare the embedded project meshes to the repository STLs and verify the expected objects, first-layer extrusion, bed bounds, and G-code checksum.

**This handle has not been printed yet.** Hardware fit, wire holding force, repeated bending, stop strength, and long-term clamp relaxation remain physical checks.

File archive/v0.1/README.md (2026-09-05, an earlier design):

# Grape Grasper v0.1

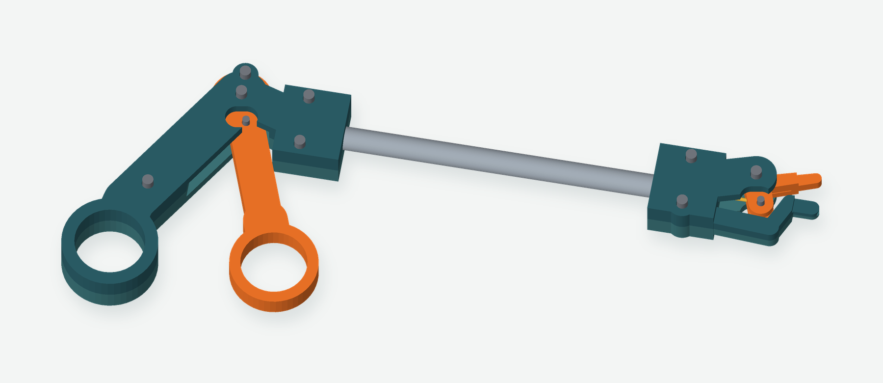
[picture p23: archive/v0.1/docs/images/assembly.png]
Full precision grasper assembly with open jaws, finger loops, metal shaft, and linkage hardware


*Full CAD assembly with the jaws open. Teal and orange parts are 3D printed; the metal shaft and fasteners are purchased hardware.*

A short, manually operated grasper for dexterity and precision-gripping experiments. Squeezing the finger loops pulls a wire through a metal tube and closes the upper jaw. Spreading the loops pushes the wire and opens it again. No motor, cable housing, tiny return spring, or electrical alligator clip is required.

**Status:** modeled and checked digitally; not yet printed or physically tested. This is a first bench prototype. The main uncertainties are print fit, wire-eye fabrication, joint friction, and how reliably the blunt tips grip small objects.

## What is included

- `precision-grasper.js`: editable JSCAD source, with assembly, individual-part, and print-layout views. The opening slider moves the grip and jaw together.
- Six individual STLs: `handle-a`, `handle-b`, `nose-a`, `nose-b`, `trigger`, and `jaw`. Print **one of each**. A and B are mirrored partners, not duplicates.
- `layout.stl`: all six printed parts arranged separately, approximately **195 × 111 mm**, with their lowest points at Z=0. Center it on your slicer's bed; do not also print the individual files.
- `mesh-checks.json` and `motion-checks.json`: digital verification results.
- [Fox.Build A1 print package](prints/fox-build-a1/PRINT-GUIDE.md): sliced PLA project, microSD G-code, toolpath previews, and setup instructions.

The grey tube and pins and gold pushrod in the assembly view are purchased hardware. They are excluded from the supplied STLs. Use the supplied STLs for the first print; their coincident triangle edges have been stitched and checked. Direct JSCAD re-exports may need the same mesh cleanup after edits.

<!-- STL-GALLERY:START -->
<!-- Generated by scripts/render_stls.py; do not edit this section. -->
## STL previews

Print one of each individual part, **or** the combined layout. Dimensions are the STL bounds; previews are individually scaled.

### Handle A

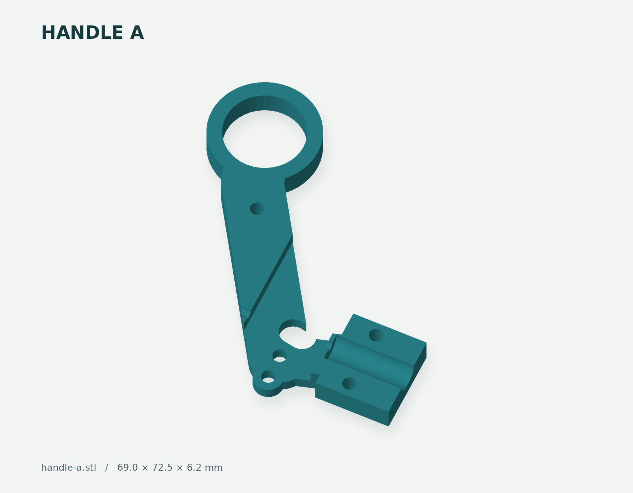
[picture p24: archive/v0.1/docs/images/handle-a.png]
handle-a STL preview


### Handle B

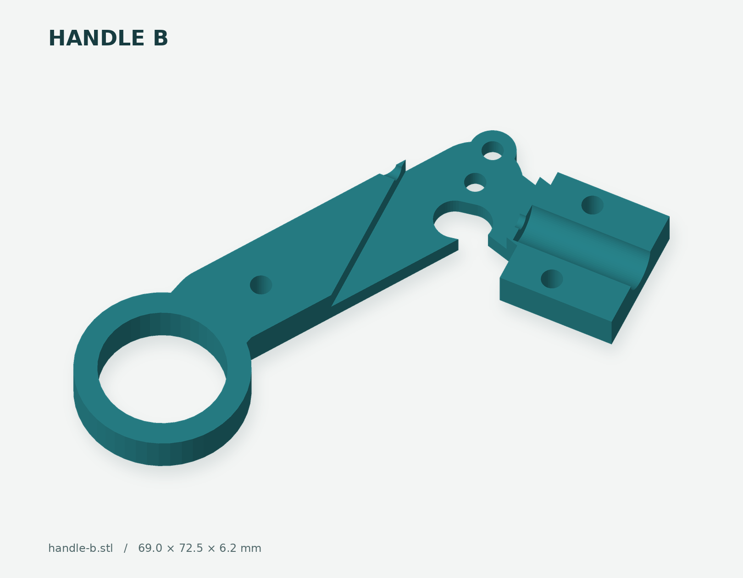
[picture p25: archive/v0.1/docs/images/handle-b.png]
handle-b STL preview


### Jaw

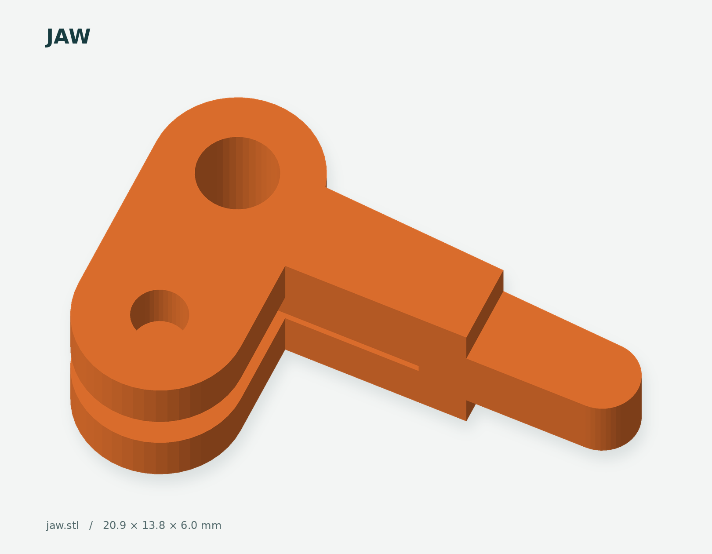
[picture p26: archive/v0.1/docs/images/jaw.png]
jaw STL preview


### Layout

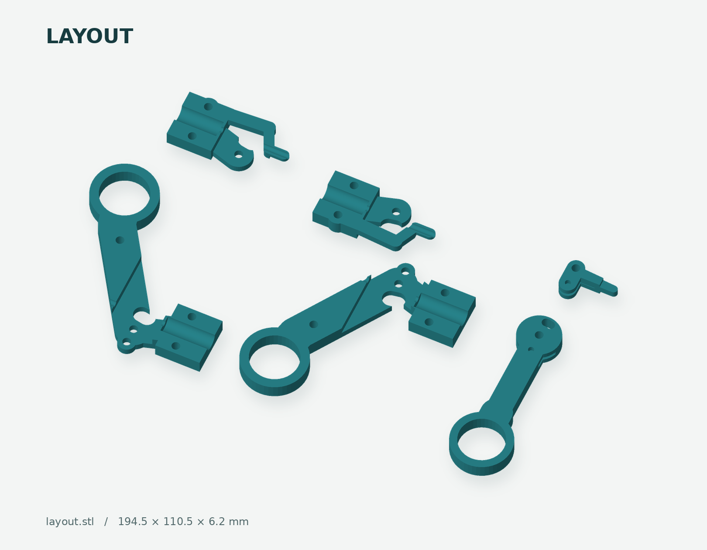
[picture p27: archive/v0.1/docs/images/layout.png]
layout STL preview


### Nose A

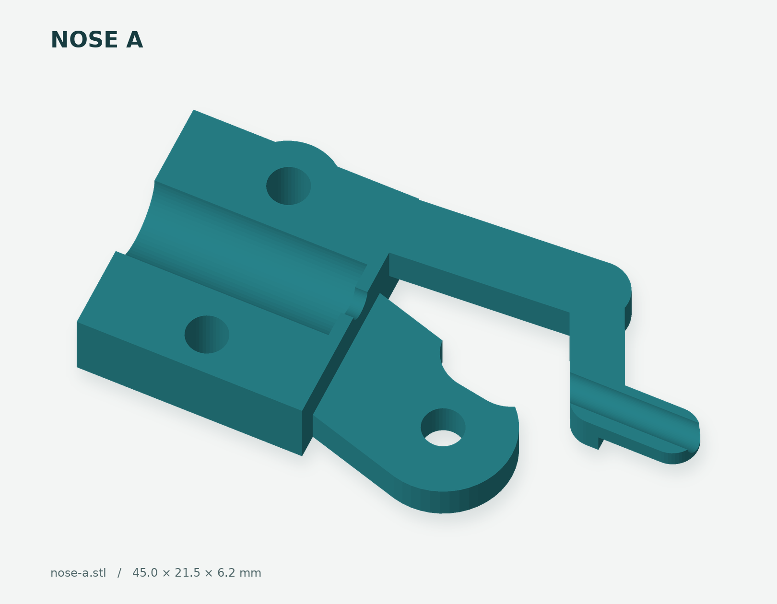
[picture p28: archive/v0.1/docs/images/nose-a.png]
nose-a STL preview


### Nose B

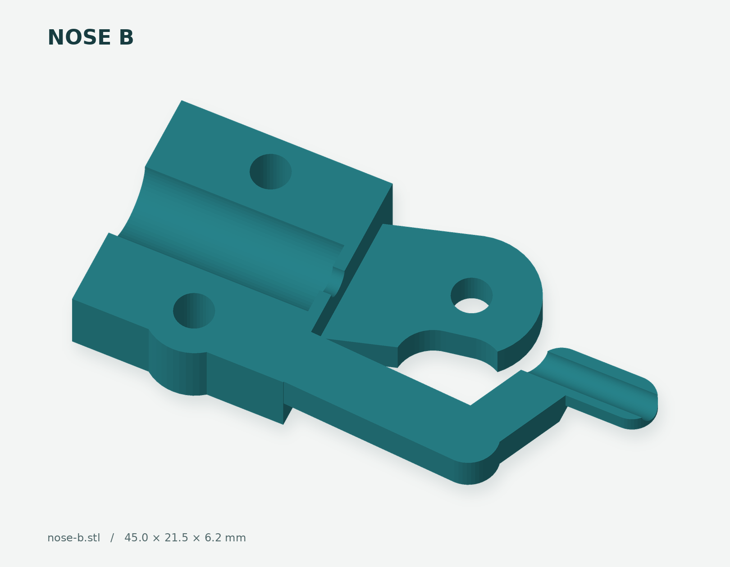
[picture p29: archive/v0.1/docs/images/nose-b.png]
nose-b STL preview


### Trigger

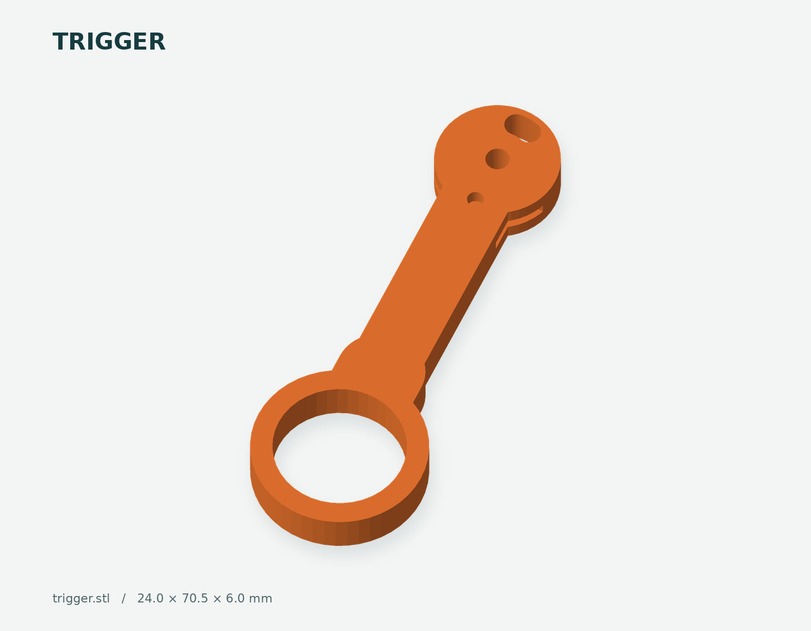
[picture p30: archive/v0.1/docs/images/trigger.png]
trigger STL preview

<!-- STL-GALLERY:END -->

## Parts to buy or find

Buy **one of each of the three products below**. Their full-pack subtotal was **$20.67** on Amazon on September 5, 2026, excluding tax, any shipping charges, tools, filament, and socket shims. Prices and availability can change; check the selected offer on Amazon before ordering.

Amazon links below are affiliate links. As an Amazon Associate I earn from qualifying purchases.

| Product to buy | Specification and use | Pack price |
|---|---|---:|
| [K&S 8106 round aluminum tube — 1 tube](https://www.amazon.com/dp/B00FZS20P0?tag=rickcarlino-20) | **1/4 inch (6.35 mm) OD × 0.014 inch wall × 12 inches long**. Calculated nominal ID is **5.64 mm**, above the required 4.8 mm. Cut one **116 mm** piece and deburr it. This is the lower-cost aluminum option for the metal shaft. | **$6.19** |
| [K&S 5497 music wire — 4 lengths](https://www.amazon.com/dp/B002WXPNA0?smid=A2E137HZ093DQ5&psc=1&tag=rickcarlino-20) | Select **0.039 inch OD × 12 inches long**, approximately **0.99 mm diameter**. Use about **180 mm** before forming the eyes. This is carbon spring steel for the dry internal linkage, not the contact tips. The quoted offer is from **Hobbylinc**. | **$6.29** |
| [HanTof 900-piece hex socket head cap screw, nut, and washer assortment](https://www.amazon.com/dp/B0FF4RH81S?tag=rickcarlino-20) | Select **900-Pieces Set**, with M2, M2.5, and M3 hardware and black Grade 12.9 alloy-steel cap screws. The listed contents include **25 × M3 × 20 mm**, **25 × M2 × 12 mm**, **100 nuts and 100 flat washers of each size**, plus hex keys. One kit covers all the fasteners below. | **$8.19** |
| **Total: one tube pack + one wire pack + one hardware kit** | Extra wire and fasteners remain for spares and later builds. | **$20.67** |

**Shipping:** The selected Hobbylinc wire offer included free shipping, with an estimated arrival of September 22, 2026. The tube and hardware kit were shipped by Amazon, with free shipping offered through Prime or on qualifying Amazon-shipped orders over $35. Their combined eligible subtotal here is only **$14.38**, so free shipping for those two items is not assumed in the price above. Confirm delivery dates and charges at checkout.
concord grape
### Fasteners used from the kit

| Component | Needed for one grasper | Included in the selected kit |
|---|---|---|
| M3 × 20 mm machine screws | **8**: two pivots, one travel-stop pin, four tube-socket screws, one fixed-grip screw | 25 |
| M3 nuts | **8** | 100 ordinary hex nuts; Nyloc nuts are not included |
| M3 thin flat washers | Approximately **16** | 100 |
| M2 × 12 mm linkage screws | **2**, through the bent wire eyes and small forked cranks | 25 |
| M2 nuts | **2** | 100 |
| M2 thin flat washers | Approximately **4** | 100 |

Use M2 screw heads and nuts under **6 mm across**. Keep the pivots and linkage joints free to move; do not tighten them until they bind. Nyloc nuts remain an optional alternative for retaining the lightly tightened M3 pivot and stop screws and are not part of this budget cart.

### Supplies excluded from the shopping subtotal

- **Socket shims:** a little thin tape or paper. The tube bores are 6.65 mm for print clearance; use shims until the sockets grip the tube without crushing the plastic. These are still needed for assembly even when already on hand.
- **Filament:** allow **30–40 g** including supports. PLA for the first fit test; PETG is an alternative after fit is established.

A 6 mm tube can be used by changing `P.tubeOD` and regenerating the housing meshes; do not scale every part to fit it. The selected 6.35 mm OD tube matches the supplied design without that change.

Tools: small saw or tubing cutter, file/deburring tool, ruler or calipers, two pairs of pliers, hardened-wire cutters, appropriate screwdrivers, and a small drill bit or hand reamer for cleaning holes. Music wire is harder to bend than soft craft wire; practice on an offcut before making the final linkage. A straight 1 mm stainless wire with comparable stiffness is another option, but soft wire may buckle when opening.

## Print setup

### Prepared plate for Fox.Build

The six individual parts are already sliced together for a **Bambu A1, 0.4 mm nozzle, ordinary PLA, and textured PEI plate**. Estimated print: **1 hour 59 minutes and 27.04 g of PLA**, including supports and brims. Settings: 0.16 mm layers, four walls, 50% gyroid infill, tree supports from the bed, and 3 mm brims. Toolpaths have been checked; physical fit still needs the first print.

- [Open the Bambu Studio project](prints/fox-build-a1/grape-grasper-A1-PLA.3mf) as a project to retain all six parts and the saved settings.
- [Download the sliced G-code](prints/fox-build-a1/grape-grasper-A1-PLA.gcode) for microSD printing with the matching setup.
- [Read the makerspace print guide](prints/fox-build-a1/PRINT-GUIDE.md) for setup, support removal, and fit checks.

Confirm the actual nozzle, plate, and loaded material at Fox.Build. If they differ, update those settings in the project and slice again. After CAD or STL changes, regenerate the slice before printing.

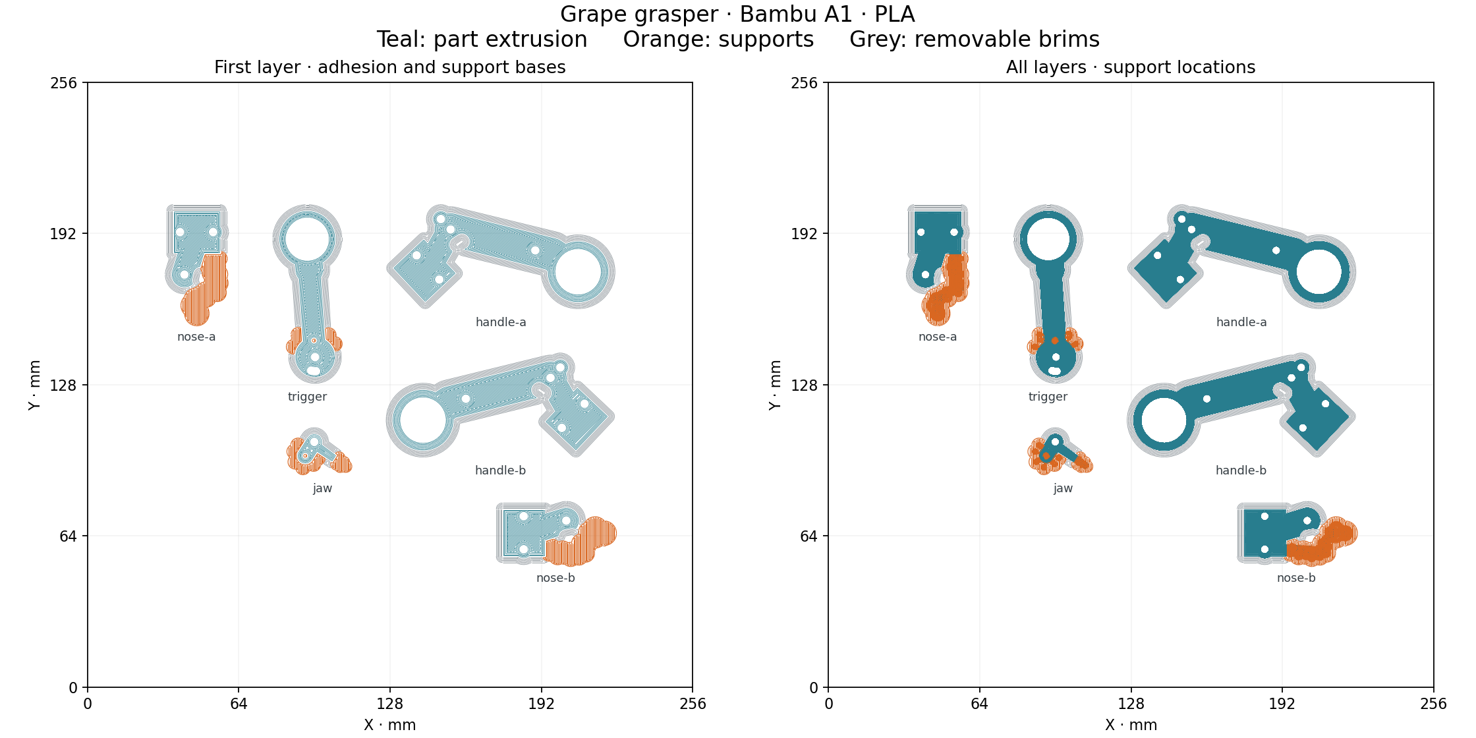
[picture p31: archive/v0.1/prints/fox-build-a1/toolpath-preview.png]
Bambu A1 first-layer and all-layer toolpaths


[Detailed support preview](prints/fox-build-a1/support-details.png) · [Slice checks and source hashes](prints/fox-build-a1/slice-checks.json)

### General print and fit guidance

Start with a **0.4 mm nozzle, 0.16–0.20 mm layers, four perimeters, and 40–60% infill**. These are proposed starting settings, not tested printer profiles. Use solid local infill around the jaw and pivot holes if available.

The files are oriented with broad faces toward the bed. The narrow jaw tip and the lower fingers on both nose halves have overhangs: **add local supports under these areas**. Inspect the slicer preview around the 1.5 mm wire slots; keep them open and remove any support or stringing afterward. This is not a support-free design.

The fixed grip opening is 19 mm diameter and the moving loop is 18 mm. Check those against your fingers before printing everything. Deburr the finger loops. Clean the nominal 3.25 mm pivot holes and 2.25 mm linkage holes until the screws slide freely. The moving parts are 6 mm thick inside a 6.4 mm fork, providing 0.2 mm nominal clearance per side. Light sanding may be required.

## Assembly

1. **Prepare the tube.** Cut it to 116 mm and deburr both inside and outside edges so they cannot scrape the wire.
2. **Form the pushrod.** Make a small eye in each end of the 1 mm wire, approximately 2.3 mm inside diameter and 4.3 mm outside diameter. Both eyes lie in the same plane and below the straight wire: the straight section meets the top of each eye. Set their centres **140 mm apart**. Thread the tube onto the wire before forming the second eye. Leave no loose sharp tail; discard any wire that cracks during bending.
3. **Attach the moving pieces.** Place one eye in the trigger's 1.5 mm central fork slot, and the other in the moving jaw's slot. Install the M2 screws through the 2.25 mm holes. Tighten the nuts enough to retain the joints while letting the eyes swivel freely; squeezing the fork cheeks onto the wire will jam it.
4. **Assemble the nose.** Put the moving jaw between Nose A and Nose B. The narrow upper tip faces the stationary lower tip. Install its M3 pivot. The large window below the pivot gives access to the M2 linkage screw. Fit the two nose socket screws loosely.
5. **Assemble the handle.** Sandwich the trigger between Handle A and Handle B. Install the M3 pivot, the second M3 screw through the curved travel-stop slot above it, the fixed-grip screw, and the two socket screws. Pivot and stop nuts should retain the parts without pinching the trigger.
6. **Align the tube and housings.** With both mechanisms closed, set the main pivot centres 140 mm apart. Each tube end is then 12 mm toward the shaft from its corresponding pivot. The tube sits approximately 17 mm into the handle socket and 15 mm into the nose socket, leaving about 84 mm exposed between housings. Keep the grip and jaw in the same plane.
7. **Secure the tube.** Add thin shims at the two sockets until the tube cannot rotate or slide under light hand force. Snug the four socket screws. The housings have clearance bores, not interference-fit clamps; the shims are part of this prototype's retention method.
8. **Set the jaw contact.** Close gently. Both tips should meet before any serious load develops. If they do not, adjust the eye spacing or housing position slightly and re-secure the tube. Do not use finger force to compensate for a badly adjusted rod.
9. **Cycle before gripping.** Open and close slowly at least 20 times. Confirm the wire does not bow, catch at a socket, or scrape a screw. Test gripping a thin paper strip, then practice picking up and placing small lightweight objects. Apply gentle pressure and check that the tips hold securely without damaging the object.

The stock eye length is set by bending, not by a threaded adjuster. A threaded RC linkage can be added in a later revision if repeated fine adjustment is needed.

## Motion and fit

The two cranks have the same 7 mm radius. With the pivots and rod-eye centres both spaced 140 mm apart, the linkage is a parallelogram: the trigger and jaw rotate together.

At 20 degrees, the calculated wire travel is **2.39 mm**, the opening at the 16 mm tip station is **5.65 mm**, and the finger-loop centre moves about **17.1 mm** sideways. The tip contact width is approximately 3 mm. The grip's curved slot limits nominal rotation to 0–20 degrees; fastener clearance adds a little play. This mechanism multiplies hand force, so squeeze lightly.

Digital checks found zero modeled intersections between the moving parts and frames, or between the rod/tube and printed parts, at each whole degree from 0 through 20. The six parts do not overlap in the print layout. Every supplied individual STL is one watertight, consistently wound solid; the layout contains six. Small coincident-edge corrections during export changed part volumes by less than 0.003 mm³ each. These checks do not establish strength, wear, tolerances on your printer, or physical gripping performance. Screw heads, washers, nuts, and the bent-wire cross section are simplified in the assembly display.

## Contact surfaces and cleaning

Use the first print for fit checks and gripping practice with paper strips or small lightweight objects. Inspect the contact surfaces for rough edges and trapped debris before each session. Removable metal or silicone tips could be explored in a later revision; alternative tip materials and attachments have not been validated in v0.1.

After a practice session, remove the nose screws and jaw, clean out residue, and dry all parts and the internal wire. Replace cracked or rough tips rather than sharpening them into teeth. The removable nose is intended to make tip experiments inexpensive.

## Rebuild the screenshots

The individual-part and layout PNG previews are rendered directly from the supplied STL meshes with orthographic projection, directional lighting, and consistent part colors. The image at the top uses the full JSCAD assembly, including the purchased hardware. The commands below rebuild the STL gallery. Python 3.10+ and Make are required; rendering is headless and needs no browser, GPU, or CAD application.

```sh
make setup
make screenshots PYTHON=.venv/bin/python
```

The default `make` target also builds screenshots. If NumPy and Pillow are already installed, run `make` directly. Use `make screenshots-force PYTHON=.venv/bin/python` to regenerate every STL preview.

The build discovers all `.stl` files recursively (case insensitive, excluding hidden directories), writes previews to `docs/images/`, and refreshes the gallery in this README. Unchanged meshes reuse their images; changes to the renderer rebuild all previews. Keep the generated PNGs with the README so the guide works without running the build. Edit instructions outside the `STL-GALLERY` markers; content inside them is generated. This target renders the existing STLs; it does not regenerate meshes from JSCAD.

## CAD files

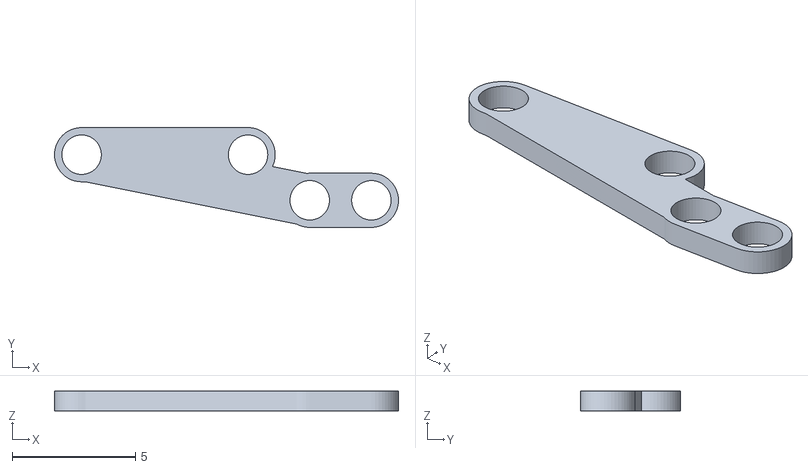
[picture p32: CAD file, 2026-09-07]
concepts/metal-head-v03/stl/cheek-a.stl
13.9 x 4.05 x 0.8

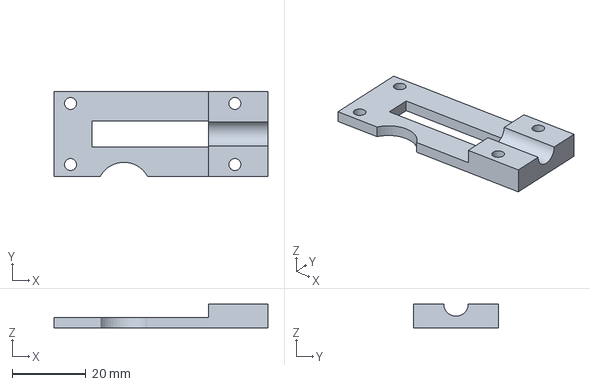
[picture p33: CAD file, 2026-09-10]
designs/guided-wire-handle/bambu/guided-wire-cover-corrected-A1-PLA.3mf
58.2 x 23.0 x 6.45 mm

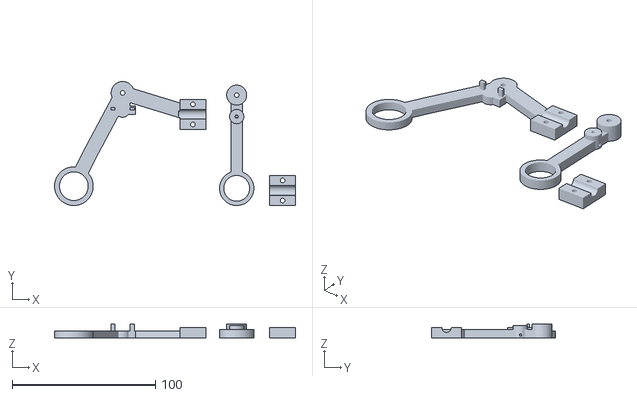
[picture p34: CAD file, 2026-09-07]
layout.stl
168.0 x 86.5 x 10.0

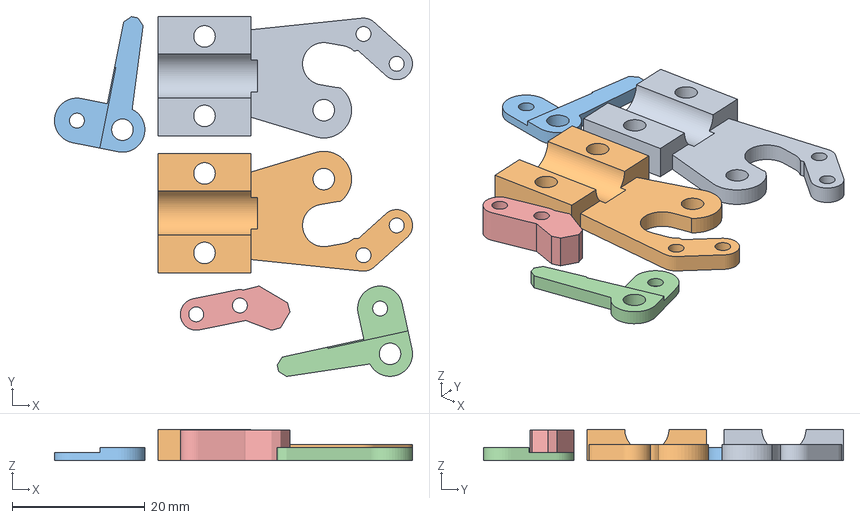
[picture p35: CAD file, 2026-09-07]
prints/fox-build-a1-head-v02/grape-grasper-head-v02-A1-PLA.3mf
54.1 x 54.3 x 4.70 mm
nose-a.stl
nose-b.stl
jaw-a.stl
jaw-b.stl
fixed-jaw.stl

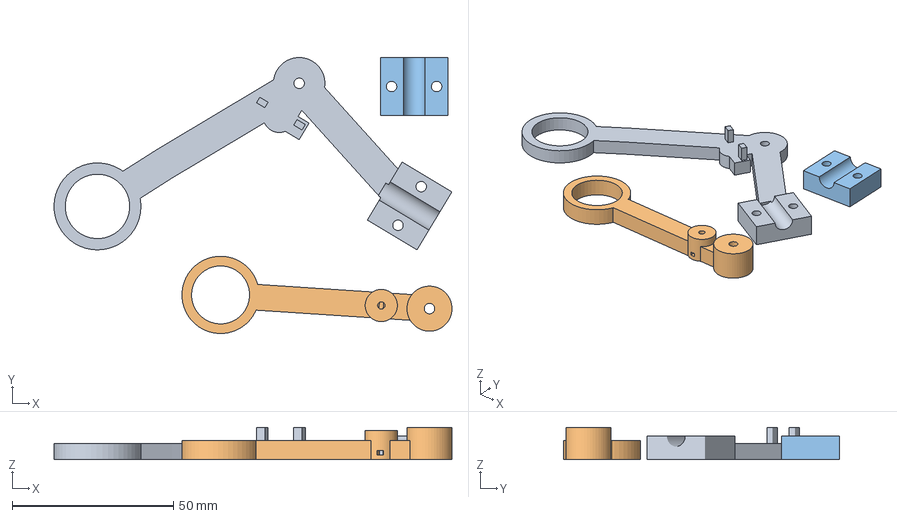
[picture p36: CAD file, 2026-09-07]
prints/fox-build-a1-lever/grape-grasper-lever-A1-PLA.3mf
123.6 x 85.7 x 10.0 mm
fixed-grip.stl
squeeze-lever.stl
tube-cap.stl

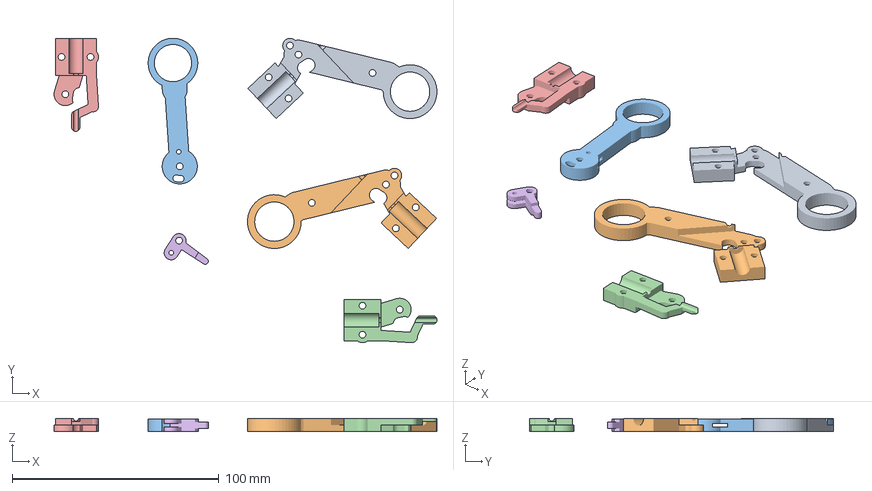
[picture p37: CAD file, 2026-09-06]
prints/fox-build-a1/grape-grasper-A1-PLA.3mf
185.0 x 147.1 x 6.20 mm
handle-a.stl
handle-b.stl
trigger.stl
nose-b.stl
nose-a.stl
jaw.stl

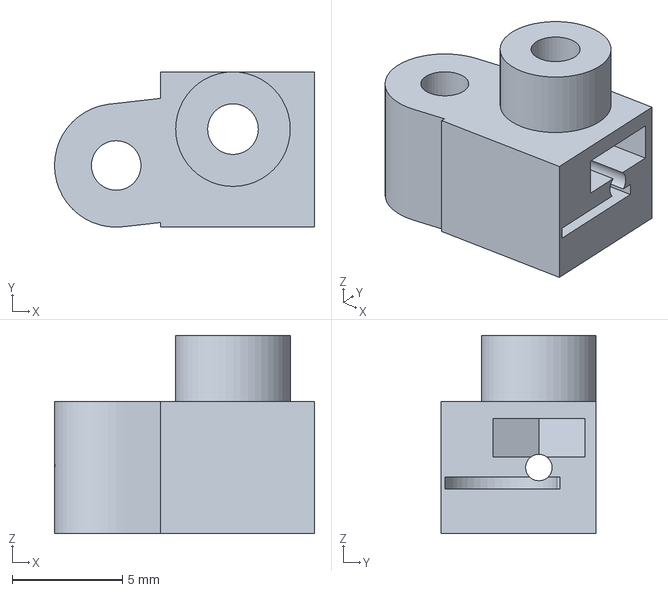
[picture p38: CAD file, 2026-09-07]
upgrades/adjustable-handle/prints/clamp-test/clamp-test-A1-PLA.3mf
11.8 x 7.05 x 9.00 mm

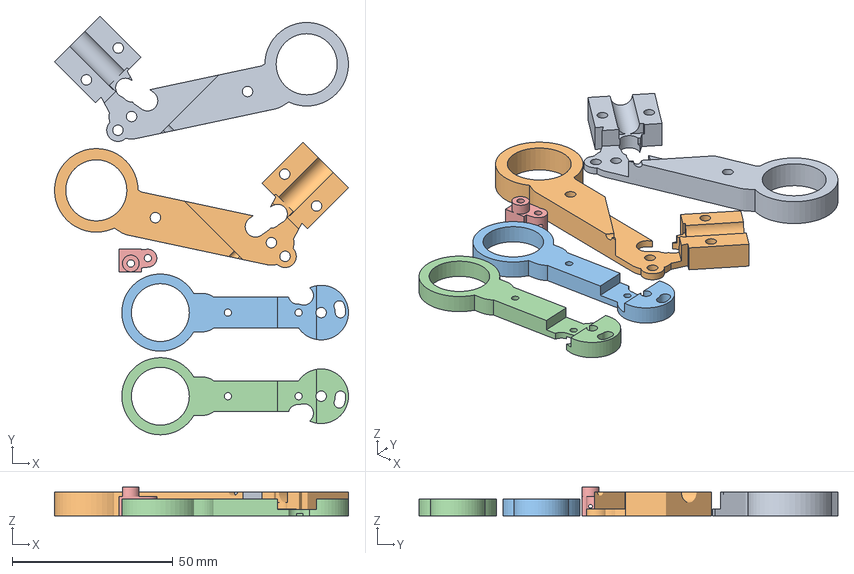
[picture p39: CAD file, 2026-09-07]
upgrades/adjustable-handle/prints/full/grape-grasper-adjustable-handle-A1-PLA.3mf
91.4 x 130.2 x 9.00 mm
handle-b.stl
handle-a.stl
trigger-a.stl
trigger-b.stl
carrier.stl

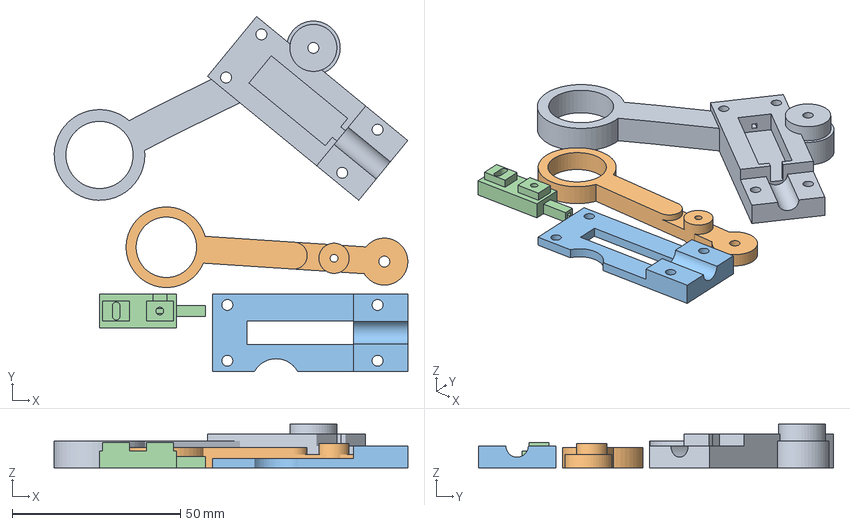
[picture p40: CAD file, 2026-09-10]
designs/guided-wire-handle/bambu/guided-wire-handle-A1-PLA.3mf
105.2 x 105.6 x 13.0 mm
frame.stl
lever.stl
cover.stl
carriage.stl

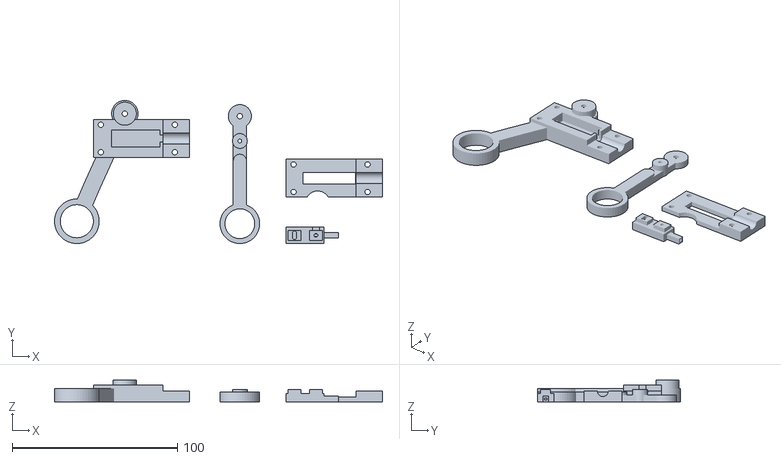
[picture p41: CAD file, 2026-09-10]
designs/guided-wire-handle/stl/layout.stl
198.2 x 86.5 x 13.0

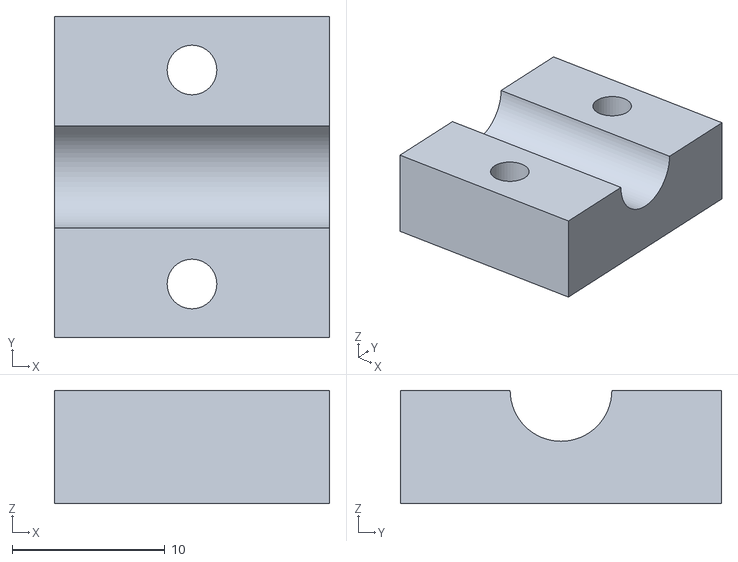
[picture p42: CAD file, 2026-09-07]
tube-cap.stl
18.0 x 21.0 x 7.40

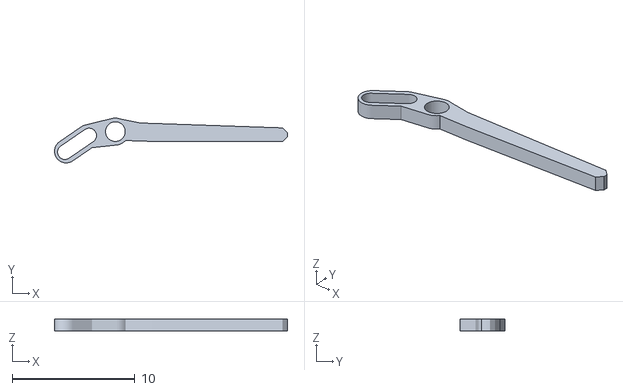
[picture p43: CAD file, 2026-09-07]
concepts/metal-head-v03/stl/moving-jaw.stl
19.0 x 3.65 x 1.00

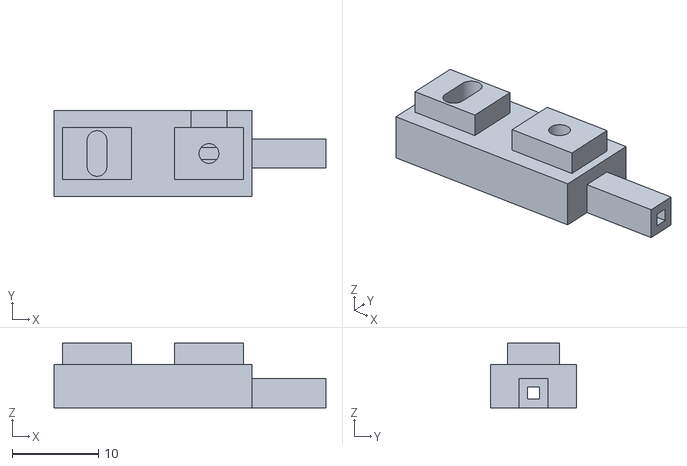
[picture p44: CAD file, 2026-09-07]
designs/guided-wire-handle/stl/carriage.stl
31.6 x 10.0 x 7.50

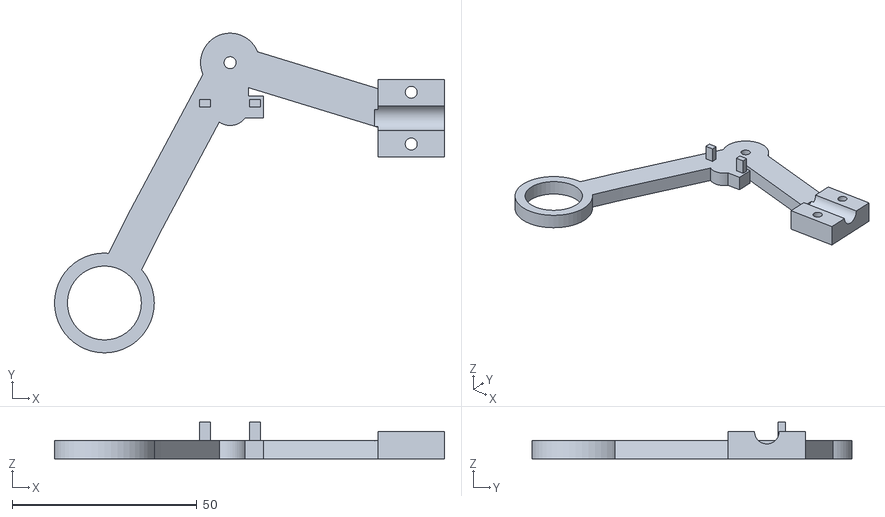
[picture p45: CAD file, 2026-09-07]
fixed-grip.stl
105.5 x 86.5 x 10.0

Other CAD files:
designs/guided-wire-handle/stl/cover.stl
concepts/metal-head-v03/stl/cheek-b.stl
concepts/metal-head-v03/stl/fixed-jaw.stl
designs/guided-wire-handle/stl/lever.stl
archive/v0.1/handle-a.stl
archive/v0.1/handle-b.stl
archive/v0.1/jaw.stl
archive/v0.1/layout.stl
archive/v0.1/nose-a.stl
archive/v0.1/nose-b.stl
archive/v0.1/trigger.stl
concepts/metal-head-v03/stl/insert.stl
designs/guided-wire-handle/stl/frame.stl
fixed-jaw.stl
head-layout.stl
jaw-a.stl
jaw-b.stl
jaw.stl
nose-a.stl
nose-b.stl
squeeze-lever.stl

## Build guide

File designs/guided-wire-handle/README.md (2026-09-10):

# Guided-wire lever handle — 6 mm travel

Full assembly with the guided-wire handle and existing v2 head

**Cover corrected September 9, 2026.** The earlier printable cover was accidentally mirrored, so its circular relief landed on the wrong side when fitted. If you already printed the 6 mm handle, print only the [replacement cover](bambu/guided-wire-cover-corrected-A1-PLA.3mf): **30 min, 4.83 g PLA**. The frame, lever, and carriage STLs are unchanged.

For a new handle, print all four parts below. This revision provides the measured 6 mm wire movement of the assembled v2 head and reuses the existing head, 116 mm metal tube, wire, and hardware.

[6 mm Bambu A1 project](bambu/guided-wire-handle-A1-PLA.3mf) · [JSCAD source](guided-wire-grasper.js) · [Four-part STL layout](stl/layout.stl)

The handle has been printed; fitting exposed the reversed cover. **The corrected cover is digitally checked and sliced, but has not yet been printed.**

## What changed

Handle with its guide cover fitted

- **6.0 mm working wire travel**, with 6.4 mm between mechanical stops. The 0.2 mm margin at each end leaves room for adjustment.
- **About 4.3:1 leverage** from the 65 mm finger arm and 15 mm drive arm. The finger ring moves approximately 26 mm for the working stroke, plus reversal play.
- **A telescoping wire guide:** the green carriage has a 3.4 mm square nose that slides inside the metal tube. Its overlap is 0.6–6.6 mm during the working stroke, so there is no bare-wire gap between the carriage guide and tube. Overlap remains 0.4 mm at the rear hard stop.
- **A straight through-hole:** wire passes through the carriage and exits the rear of the frame. Excess wire can protrude while you adjust it. The drive screw ends above this passage and cannot obstruct it in the modeled motion.

Section showing the wire clamp, guide entering the tube, and excess wire exiting the back

The M2 drive screw is fastened into a nut in the orange lever. Its tip engages the carriage slot by 3.5 mm, with 0.5 mm clearance above the slot floor and 1.8 mm above the wire. A separate M2 screw clamps the wire in the carriage. No handle-end loop is needed.

The 2 mm drive screw runs in a 2.3 mm-wide slot: nominal reversal play is 0.3 mm at the wire, or about 1.3 mm at the finger ring. The stops limit travel, not gripping force.

In JSCAD, select **6 mm guided-wire handle** or **Cover removed**, then move **Wire advance (mm)** from 0 to 6. The full assembly view is a closed reference. The builder's measured travel sets the handle stroke; the old head CAD does not establish the as-built relationship between wire travel and jaw angle.

## Print at FOX.BUILD

Open [guided-wire-handle-A1-PLA.3mf](bambu/guided-wire-handle-A1-PLA.3mf) **as a project** in Bambu Studio. This file contains the revised four models, settings, and freshly sliced G-code. Its process profile is **Grasper 6mm cover rotation fix 2026-09-09 - A1 PLA**. The [cover-only project](bambu/guided-wire-cover-corrected-A1-PLA.3mf) uses the same settings and contains just the replacement part. Earlier downloaded projects with the old profile still contain the mirrored cover; download the corrected file again.

- Bambu A1, **0.4 mm nozzle**, Generic PLA, textured PEI plate.
- 0.16 mm layers; 0.20 mm first layer; five walls; 60% gyroid; 2 mm brims; supports off.
- Estimate: **2 hr 15 min, 28.55 g PLA**. Confirm the installed nozzle and filament.
- Keep the supplied orientations. Frame, lever, and carriage print flat; the cover prints upside down using a 180° rotation about its length, preserving its handedness. Fit it with the tube saddle facing down and the circular relief beside the lever pivot. The carriage's narrow guide starts on the same bed plane as its body.
- Clean the small wire holes and nut pockets after printing. They contain short bridges. Leave timelapse off. The headless project has no native thumbnail; reslicing in Bambu Studio generates its preview.

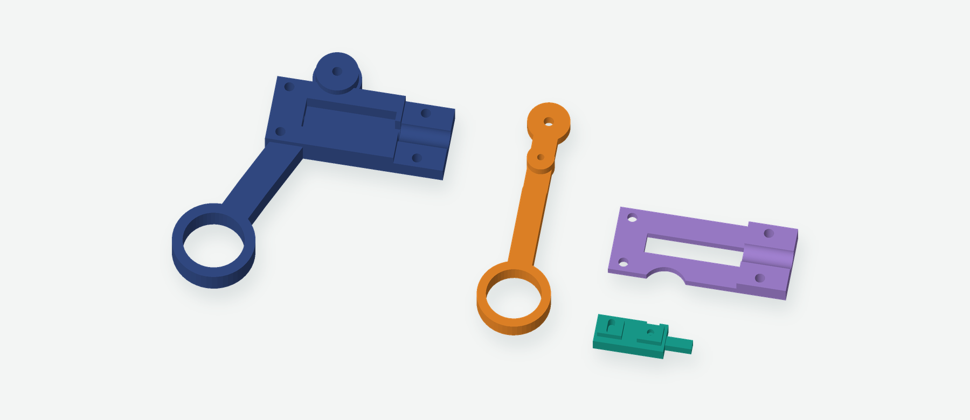
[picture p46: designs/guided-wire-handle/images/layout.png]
Four parts in their print orientations


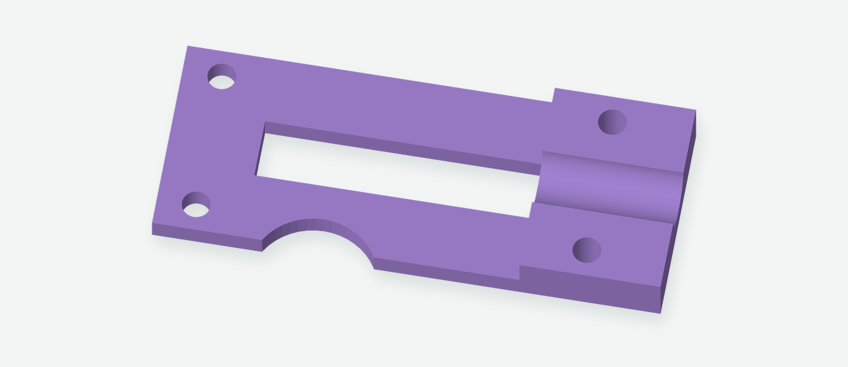
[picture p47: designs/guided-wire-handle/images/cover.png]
Corrected purple cover in its print orientation, with the tube saddle facing upward


The cover above is shown as printed. Turn it over during assembly: the saddle faces the tube and the circular relief clears the lever pivot. [Cover-only toolpaths](bambu/cover-toolpath-preview.png) · [Cover-only slice checks](bambu/cover-slice-checks.json).

Individual STLs: [frame](stl/frame.stl), [lever](stl/lever.stl), [carriage](stl/carriage.stl), [cover](stl/cover.stl). [Verified toolpath preview](bambu/toolpath-preview.png).

## Hardware for this handle

| Hardware | Quantity | Use |
| --- | ---: | --- |
| M3 × 20 mm screws and M3 nuts | 5 each | Four cover screws and lever pivot |
| M3 flat washers | 10 | Two at each cover screw; one above and one below the lever |
| M2 × 12 mm screws and M2 nuts | 2 each | Wire clamp and lever drive pin |

The washer below the lever is **0.5 mm thick, 7 mm OD**. The other modeled M3 washers are also 0.5 mm thick. The pivot nut sits inside the underside of the frame without an outside bottom washer. M2 nuts are nominally 4 mm across flats × 1.6 mm thick. No extra purchased parts are needed.

## Assembly and adjustment

1. Remove brims. Clean the carriage rails, nut pockets, and wire passage. With the clamp screw backed out, pass a straight piece of the actual wire completely through the carriage. Also check the 1.5 mm rear frame hole. Do not drill into the drive-slot floor above the wire passage.
2. Check that the carriage's square nose slides freely into the deburred tube. It has approximately 0.42 mm clearance at its corners in the nominal 5.64 mm tube bore. Remove print burrs if needed; do not force it.
3. Insert an M2 nut into the side of the lever's drive boss and another into the carriage. Seat the lever's M2 × 12 screw fully against its raised boss. Start the carriage clamp screw but leave its wire passage open.
4. Seat the M3 pivot nut in the frame's underside pocket. Lower the carriage into the open frame **before inserting the tube**. Slide the tube over the projecting guide until it reaches the shoulder. Feed the straight wire end from the tube, through the carriage, and out the rear frame hole. Keep the existing head-end attachment.
5. Turn the cover over so its tube saddle faces down and its circular relief clears the frame’s raised lever-pivot boss. Fit it with four M3 screws, nuts, and outside washers. Tighten evenly and check that the carriage slides freely. Nominal clearance is 0.25 mm at each side and 0.35 mm beneath the cover. If the tube slips after the clamp faces meet, use a thin paper or tape wrap at the socket instead of tightening harder.
6. Put the 0.5 mm washer on the pivot boss. Fit the lever with its drive screw in the carriage slot, then add the top washer and M3 screw. **Adjust the pivot for free rotation. Fully tightening it can bind the lever; this is not a shoulder-bolt joint.**
7. Close the actual jaws gently. Position the carriage about **0.2 mm forward of its rear stop**, then tighten the wire clamp gently. Leave the excess wire sticking out of the back while fitting; there is no prescribed tail length and no need to pull a loop through the handle.
8. Mark the wire at the rear exit and measure 6 mm of advance while opening the lever. Check that the head reaches its intended opening and returns without wire slip or rubbing. If the head stops first, release the lever and adjust the wire; do not force the mechanical stops against a closed jaw. Trim the free tail later only if desired.

## Checks and limitations

[Handle motion checks](checks.json) passed at **122 positions**, covering the full 0–6 mm stroke in both pushing and pulling contact states. Additional checks cover the wire exit, screw and nut insertion, carriage drop-in, tube insertion, drive contact, and mechanical stops.

[Mesh and layer checks](mesh-checks.json) passed for four single-body watertight parts with no floating layer islands. The saved cover STL is now turned back into assembly position using only a rotation and translation, checked against the intended shape, and checked for frame overlap. A deliberately mirrored cover must fail the same fit check. [Bambu checks](bambu/slice-checks.json) verify matching embedded meshes, settings, first-layer paths for all parts, bed bounds, and the G-code checksum.

The [orientation audit](../../orientation-checks.json) checked all nine current parts against the intended assembly using rotations and translations, and checked the saved Bambu models against their STLs. No other reversed parts were found. The head’s paired mirrored halves are intentional.

The existing head geometry is unchanged. Its old idealized linkage model shows small overlaps when extrapolated beyond its original range; it does not supersede the builder's measured 6 mm travel. The assembly image therefore shows the closed head, and the motion slider demonstrates the new handle independently. Check the assembled head for rubbing during the first slow cycles.

The corrected cover still needs a physical fit test, and the complete handle needs a grip test. Digital checks do not prove friction, clamp force, fatigue, or buckling resistance. The large tube bore can still allow internal wire bowing, although the telescoping nose supports the transition at the handle.

To rebuild from the repository root:

```sh
node designs/guided-wire-handle/check.cjs
node designs/guided-wire-handle/export.cjs work/guided-wire
python designs/guided-wire-handle/build.py work/guided-wire
python designs/guided-wire-handle/render.py work/guided-wire
python scripts/verify_bambu.py designs/guided-wire-handle/bambu/guided-wire-handle-A1-PLA.3mf guided --source-dir designs/guided-wire-handle/stl --output-dir work/guided-wire/verified
python scripts/verify_bambu.py designs/guided-wire-handle/bambu/guided-wire-cover-corrected-A1-PLA.3mf cover --source-dir designs/guided-wire-handle/stl --output-dir work/guided-wire/cover-verified
```

Use the existing Node and Python check/render dependencies. The [saved Bambu profiles](bambu/profiles) belong to this revision. Rebuilding STLs does not reslice the project automatically.

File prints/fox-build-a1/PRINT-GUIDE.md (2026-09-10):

> **Historical print record — superseded.** Use the [current guided-wire handle project](../../designs/guided-wire-handle/README.md) and [v2 head project](../fox-build-a1-head-v02/PRINT-GUIDE.md).

> **Superseded v0.1 head:** the first PLA print showed head failures. Use the [v0.2 head-only package](../fox-build-a1-head-v02/PRINT-GUIDE.md) for the replacement. The handle geometry is unchanged.

# Grape grasper — Fox.Build Bambu A1 print package

Prepared September 5, 2026 with Bambu Studio 2.8.2.61.

All six parts are sliced on one plate. Estimate: **1 hour 59 minutes, 27.04 g of PLA**, including supports and brims. This is a first fit-test prototype; it has not yet been physically printed or assembled.

Fox.Build lists **Bambu A1 printers with a 256 × 256 × 256 mm build volume** and accepts PLA, PLA+, and PETG: https://fox.build/equipment/bambu-a1-3d-printers/

## At the makerspace

1. Confirm the printer is an **A1 with a 0.4 mm nozzle**, the installed plate is **textured PEI**, and the loaded filament is **ordinary PLA**. The website does not identify the installed nozzle or plate. This package assumes these three settings.
2. Open `grape-grasper-A1-PLA.3mf` in Bambu Studio **as a project**, preserving the six objects, placement, and settings. Review the Preview tab. Keep the supplied broad-face-down orientations.
3. If the nozzle, plate, or filament differs, select the actual printer/nozzle, plate, and material preset, then **Slice Plate again**. PETG needs a fresh slice with a PETG profile.
4. With the matching setup, either use Bambu Studio to send the sliced plate over the Fox.Build network, or copy `grape-grasper-A1-PLA.gcode` to the printer's microSD card and select it on the printer. Fox.Build documents both methods. Match the filament source to the spool actually loaded; leave timelapse off.
5. Enable bed leveling before printing and watch the first layer to make sure the small support bases and parts adhere.

The supplied G-code has already been sliced for the stated setup. Opening the 3MF does not require rebuilding the CAD model. The command-line export has no embedded thumbnail; the separate PNG previews show actual exported toolpaths. Bambu Studio can regenerate its native preview by slicing the project.

## Settings in the supplied slice

| Setting | Value |
| --- | --- |
| Printer | Bambu Lab A1, 0.4 mm nozzle |
| Material | Generic PLA, 1.75 mm |
| Plate | Textured PEI |
| Nozzle / bed | 220 °C / 65 °C |
| Layers | 0.16 mm; 0.20 mm first layer |
| Walls | 4 |
| Infill | 50% gyroid |
| Top / bottom | 6 / 5 layers, with 1.0 mm minimum top shell thickness |
| Supports | Automatic tree supports, build plate only |
| Support contact gap | 0.20 mm; 3 interface layers |
| Brim | 3 mm outside only, 0.10 mm separation |
| Colors / prime tower | One color; no prime tower |

## After printing

Let the plate cool, remove the parts, and carefully remove the brims and support trees. Hold each thin tip close to the support while separating it so you do not bend the tip. Inspect the nose fingers, jaw tip, and crank/trigger details for remaining support.

Clear the **1.5 mm wire slots**. Check the **3.25 mm pivot holes** and **2.25 mm link holes**; clean or ream them gently by hand if needed. Fit the 6 mm moving parts in the nominal 6.4 mm forks and confirm free movement before tightening pivot hardware. Follow the [assembly instructions in the project README](../../archive/v0.1/README.md#assembly).

## Files and checks

- `grape-grasper-A1-PLA.3mf`: editable project with six separate parts, settings, and embedded sliced G-code.
- `grape-grasper-A1-PLA.gcode`: the same unmodified G-code extracted for microSD use.
- `toolpath-preview.png`: first-layer and all-layer toolpath views; orange is support, grey is brim, teal is the part.
- `support-details.png`: detailed views of actual support paths under the raised tips.
- `slice-checks.json`: machine identity, source hashes, bounds, estimates, and validation results.

Validation: six unique objects, unchanged source triangle geometry, A1 printer identifier N2S, verified embedded G-code checksum, all object/support extrusions within the bed, and support toolpaths present for both nose parts and the jaw. Physical fit and support removal still need testing on the first print.

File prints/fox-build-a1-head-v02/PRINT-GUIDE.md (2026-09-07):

# Bambu A1 — v0.2 replacement head

This slice includes the reinforced cheek webs. Print only the five replacement head pieces. Use the current [guided-wire handle](../../designs/guided-wire-handle/README.md). An already assembled head does not need reprinting.

**Estimate: 33 minutes 33 seconds, 4.49 g of PLA.** Settings: A1, 0.4 mm nozzle, ordinary PLA, textured PEI, 0.16 mm layers (0.20 mm first), four walls, 50% gyroid, 2 mm outside brims, **supports disabled**. Nozzle 220 °C; bed 65 °C.

1. Confirm the nozzle, plate, and loaded filament match these settings.
2. Open [the 3MF project](grape-grasper-head-v02-A1-PLA.3mf) **as a project** in Bambu Studio. Keep the saved orientations and all five objects. If the printer/material/plate differs, select the correct settings and slice again.
3. Review the preview and enable bed leveling. Leave timelapse off. Send the plate through Bambu Studio, or export the sliced G-code from the supplied 3MF to the printer's microSD card. Fox.Build documents both methods on its [A1 equipment page](https://fox.build/equipment/bambu-a1-3d-printers/).
4. Watch the first layer. Each part should begin directly on the bed. Let the plate cool before removal, then trim the brims and clean the mating faces.
5. Follow the [head assembly guide](../../docs/HEAD-V02.md).

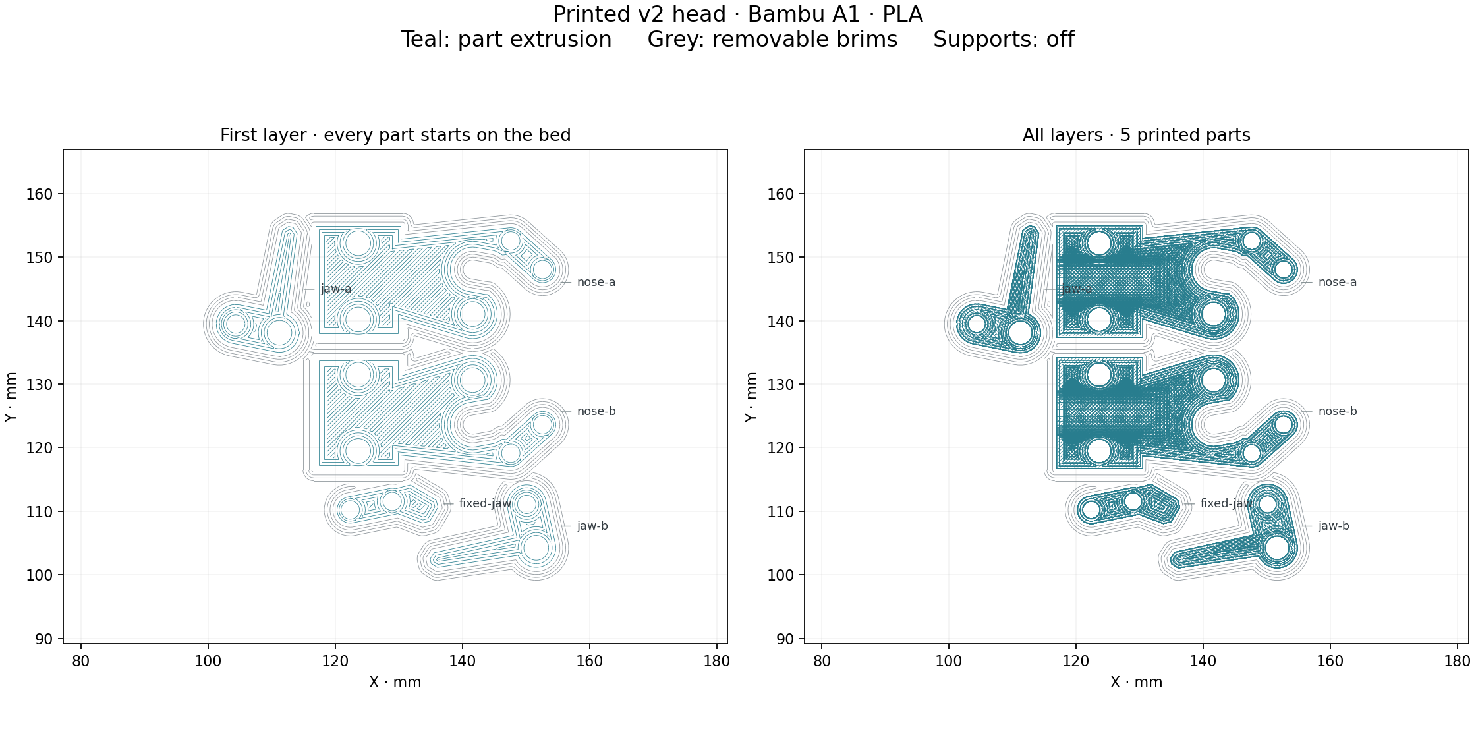
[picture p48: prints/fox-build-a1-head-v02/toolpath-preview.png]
Actual first-layer and all-layer toolpaths


The head has been redesigned to eliminate raised unsupported fingers, not just sliced with supports unchecked. The five meshes have continuous bed faces and no raised horizontal undersides. Short internal bridge regions over infill are present; no support paths are generated. The builder has printed and assembled this head.

The command-line Bambu Studio export lacks an embedded thumbnail; the separate image shows the actual exported toolpaths. The editable project includes the sliced G-code. Re-slicing in Bambu Studio regenerates its native preview. Source hashes and settings are recorded in [slice-checks.json](slice-checks.json).

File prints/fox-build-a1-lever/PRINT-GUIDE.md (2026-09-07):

# Bambu A1 — direct-clamp lever handle

Print one fixed grip, one squeeze lever, and one tube cap. Reuse the assembled v2 head and 116 mm tube; the wire may need to be longer.

**Estimate: 1 hour 32 minutes 43 seconds, 19.12 g PLA.** Bambu A1, 0.4 mm nozzle, textured PEI, 0.16 mm layers (0.20 mm first), five walls, 60% gyroid, 2 mm outside brims, supports off.

1. Open [the 3MF](grape-grasper-lever-A1-PLA.3mf) **as a project** in Bambu Studio. Confirm the actual printer, nozzle, plate, and filament match. Reslice if they differ.
2. Keep all three objects and their saved orientations. Each broad face starts on the bed. The wire passage and side-loading M2 nut pocket contain short bridges.
3. Review the toolpaths, enable bed leveling, and leave timelapse off. Send through Bambu Studio or export the sliced G-code to a microSD card.
4. Watch the first layer. Let the bed cool, remove brims, and clean the passage and nut pocket before assembly.
5. Follow the [lever-handle assembly guide](../../docs/LEVER-HANDLE.md).

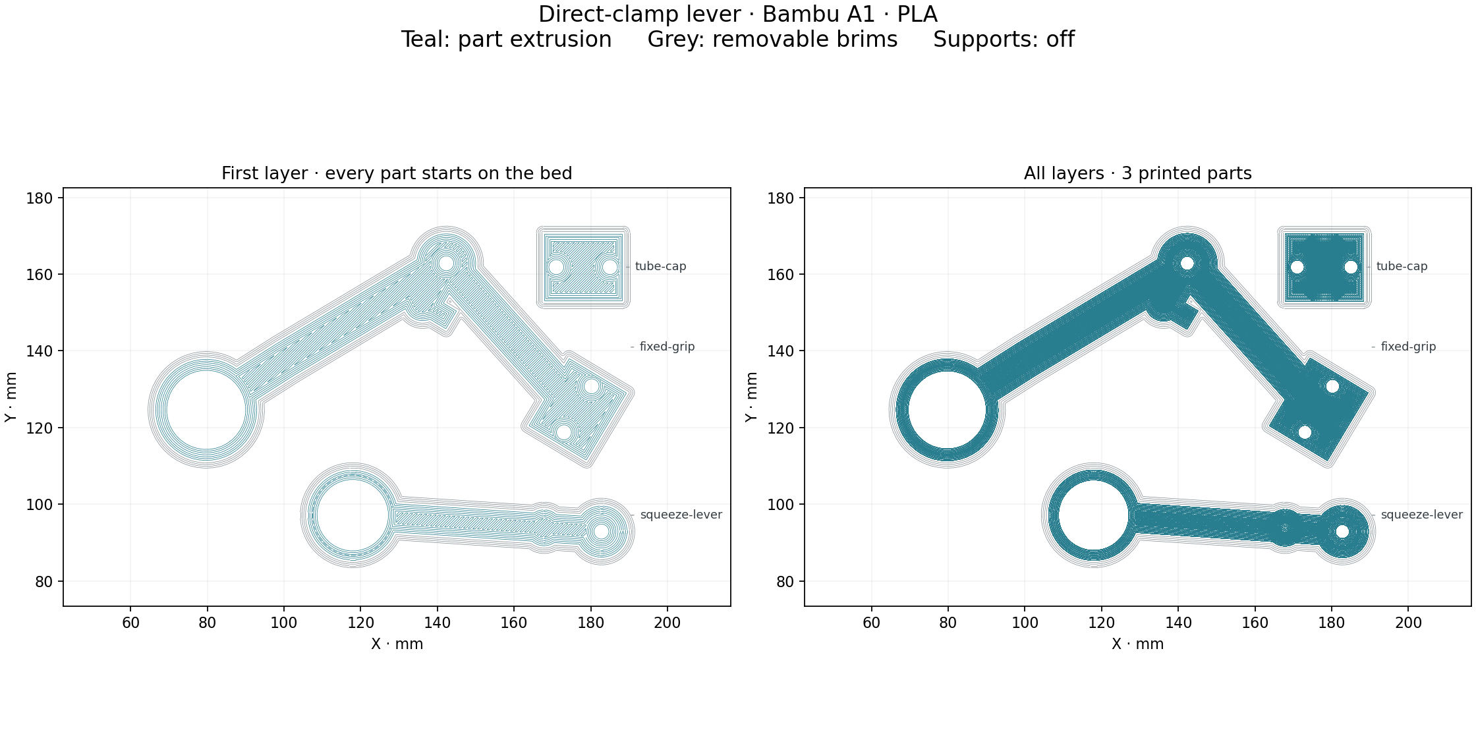
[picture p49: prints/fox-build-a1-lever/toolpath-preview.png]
Actual first-layer and all-layer toolpaths


The [slice checks](slice-checks.json) compare the actual embedded meshes with the source STLs and confirm all three objects start on the bed, the extrusion stays within the plate, supports are absent, and the G-code checksum matches. The command-line export lacks a native thumbnail; the image above comes from the actual G-code. Reslicing in Bambu Studio regenerates its own preview.

This handle is awaiting its first physical print and motion test.

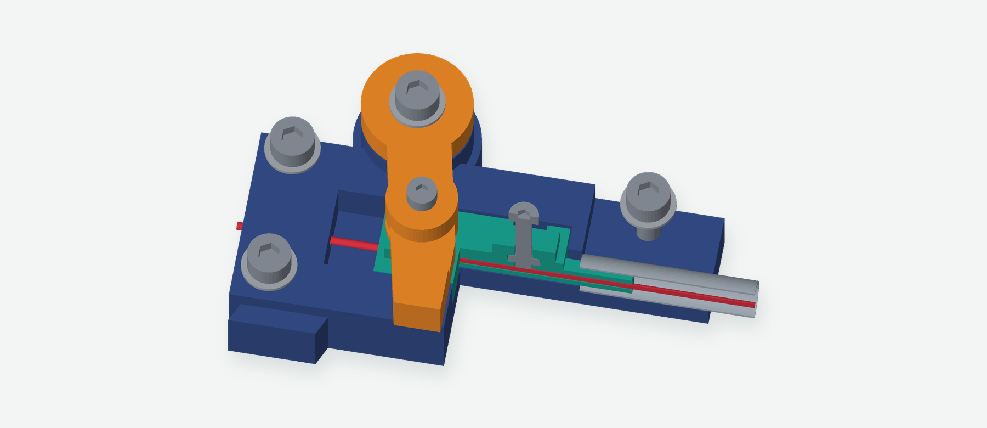
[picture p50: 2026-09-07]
designs/guided-wire-handle/images/section-6.png

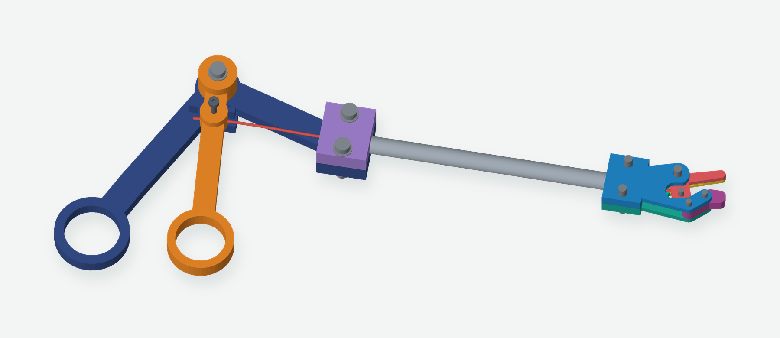
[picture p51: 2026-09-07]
docs/images/assembly.png

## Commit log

2026-09-06 v0.2 - gripper head re-write
    [fixed-jaw.stl, handle-a.stl, handle-b.stl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]
2026-09-06 Add 3mf files.
    [grape-grasper-A1-PLA.3mf, grape-grasper-head-v02-A1-PLA.3mf]
2026-09-07 Better cable travel.
    [carriage.stl, cheek-a.stl, cheek-b.stl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]
2026-09-10 Fix mirrored cover export and refresh print package
    Rotate the guide cover onto the bed without reversing its handedness. Include corrected full-handle and cover-only Bambu projects, a cover close-up, updated build and assembly notes, and an audit of the printable parts.
    Validation: 122 handle motion positions; saved-mesh orientation and layer checks; Bambu mesh and G-code checks; 23-part orientation audit; refreshed renderings and documentation links.
    [cover.stl, guided-wire-cover-corrected-A1-PLA.3mf, guided-wire-handle-A1-PLA.3mf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]
